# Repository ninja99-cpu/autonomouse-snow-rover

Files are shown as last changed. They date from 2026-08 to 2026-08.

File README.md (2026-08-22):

# Snowbot Rover

An autonomous GPS-guided snowblower rover built on ArduPilot Rover with brushless motors, skid steering, and RC override.

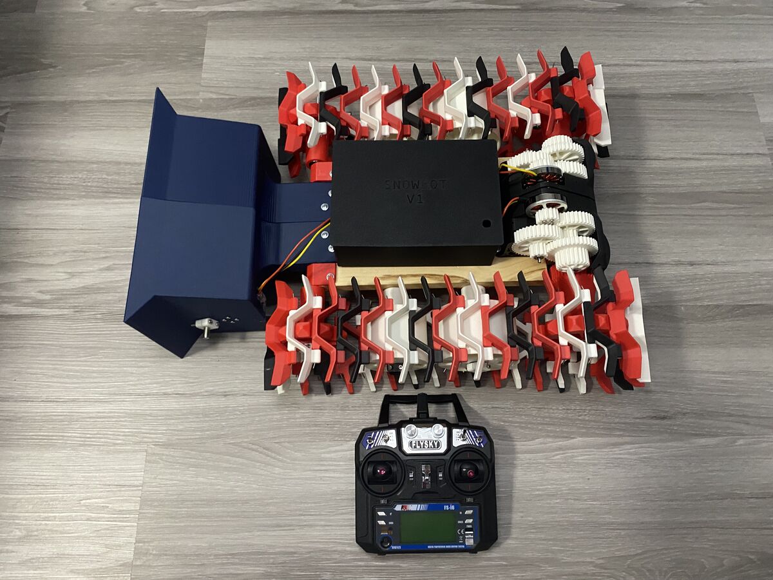
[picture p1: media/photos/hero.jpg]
Snowbot Rover


---

## Overview

Snowbot is a tracked rover designed to autonomously remove snow using a brushless impeller. It runs ArduPilot Rover on an Omnibus F4 flight controller and supports both manual RC control and GPS waypoint navigation. The project was built for an engineering fair and combines embedded systems, power electronics, robotics, and mechanical design.

---

## Features

- Skid steering via two independent brushless drive motors
- Brushless snow impeller controlled independently from the drive system
- Manual RC control via FlySky IBUS
- GPS waypoint navigation via ArduPilot Rover
- Built on the open-source RC Snowcat chassis by RCTestFlight, printed in PLA

---

## Hardware

| Component | Qty | Notes |
|---|---|---|
| 5010 Brushless Motor 360KV 2-6S | 3 | 2x drive, 1x impeller |
| 30A BLHeli ESC (bidirectional, 2-4S) | 2 | Drive motors |
| 40A Waterproof ESC (2-4S) | 1 | Impeller motor |
| Omnibus F4 Flight Controller | 1 | STM32F405 |
| 4S LiPo Battery 6000mAh XT60 | 1 | |
| Power Distribution Board | 1 | 5V regulated output for FC |
| BE-220 GPS Module | 1 | |
| FlySky FS-i6 Transmitter | 1 | |
| FlySky FS-iA6B Receiver | 1 | IBUS protocol |
| 8mm Hardened Steel Linear Bearing Rod 400mm | 4 | |
| F694zz Flanged Ball Bearings (4x11x4mm) | 12 | |
| 22x8x7 Skateboard Bearings | 16 | |
| 4mm Steel Rods (gearbox axles) | 4 | 95mm and 80mm |
| Music Wire 0.055in x 36in | 8 | ~35 x 100mm segments per track |
| Wood Plank | 1 | Chassis base |
| PLA Filament | ~1kg | All project-specific printed parts |

Full BOM in [`hardware/bom.csv`](hardware/bom.csv).

---

## Wiring

### Power
```
Battery (4S LiPo) -> PDB -> ESCs (x3)
                  -> PDB -> Flight Controller (5V)
```

### ESC Outputs

| FC Output | Assignment |
|---|---|
| M1 | Left Drive Motor |
| M2 | Right Drive Motor |
| M3 | Impeller Motor |

Each ESC: Signal (White) and Ground (Black) to FC. Red BEC wire left disconnected — FC is powered from PDB.

### RC Receiver (IBUS)
```
FS-iA6B IBUS Signal -> FC UART RX
FS-iA6B 5V         -> FC 5V
FS-iA6B GND        -> FC GND
```

### GPS
```
GPS TX  -> FC RX
GPS RX  -> FC TX
GPS 5V  -> FC 5V
GPS GND -> FC GND
```

---

## Software

ArduPilot Rover configured for skid steering. Output assignments:

| Parameter | Value |
|---|---|
| SERVO1_FUNCTION | Left Motor |
| SERVO2_FUNCTION | Right Motor |
| SERVO3_FUNCTION | Impeller Motor |

Mission Planner (Windows) was used for all configuration. QGroundControl was tested on macOS but has limited ArduPilot support.

---

## Project Status

| Feature | Status |
|---|---|
| Skid steering | Done |
| RC manual control | Done |
| Brushless motor control | Done |
| Impeller control | Done |
| ArduPilot configuration | Done |
| GPS wiring and configuration | Done |
| Autonomous waypoint navigation | Implemented, field testing pending |
| Compass / magnetometer | Not added |
| Obstacle avoidance | Planned |
| Camera system | Planned |

---

## License

MIT License — see [LICENSE](LICENSE) for details.

---

*Built by Danny Alrayyes*

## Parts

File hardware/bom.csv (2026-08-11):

Component | Quantity | Category | Notes | Source
5010 Brushless Motor 360KV 2-6S | 3 | Motors | 2x drive motors, 1x impeller motor | Amazon
30A BLHeli ESC (bidirectional 2-4S) | 2 | Electronics | Drive motors — reprogrammed for bidirectional | Amazon
40A Waterproof ESC (2-4S) | 1 | Electronics | Impeller motor | Amazon
Omnibus F4 Flight Controller | 1 | Electronics | STM32F405 — running ArduPilot Rover | Amazon
4S LiPo Battery 6000mAh XT60 | 1 | Power |  | Amazon
Power Distribution Board (PDB) | 1 | Power | 5V regulated output for FC | Amazon
BE-220 GPS Module | 1 | Navigation |  | Amazon
FlySky FS-i6 Transmitter | 1 | RC Control |  | Amazon
FlySky FS-iA6B Receiver | 1 | RC Control | IBUS protocol | Amazon
8mm Hardened Steel Linear Bearing Rod 400mm | 4 | Chassis |  | Amazon
F694zz Flanged Ball Bearings (4x11x4mm) | 12 | Bearings |  | Amazon
22x8x7 Skateboard Bearings | 16 | Bearings |  | Amazon
4mm Steel Rod - 95mm (gearbox axle) | 2 | Chassis |  | Amazon
4mm Steel Rod - 80mm (gearbox axle) | 2 | Chassis |  | Amazon
Music Wire 0.055in x 36in | 8 | Tracks | ~35 x 100mm segments per track | Great Hobbies
Wood Plank | 1 | Chassis | See original RC Snowcat design for dimensions | Home Depot
PLA Filament | ~5kg | 3D Printing | All project-specific printed parts | Amazon

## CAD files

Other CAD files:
CAD Files/Gear-cover.f3d
CAD Files/Housing-leftSide.f3d
CAD Files/Housing-rightSide.f3d
CAD Files/Impeller.f3d

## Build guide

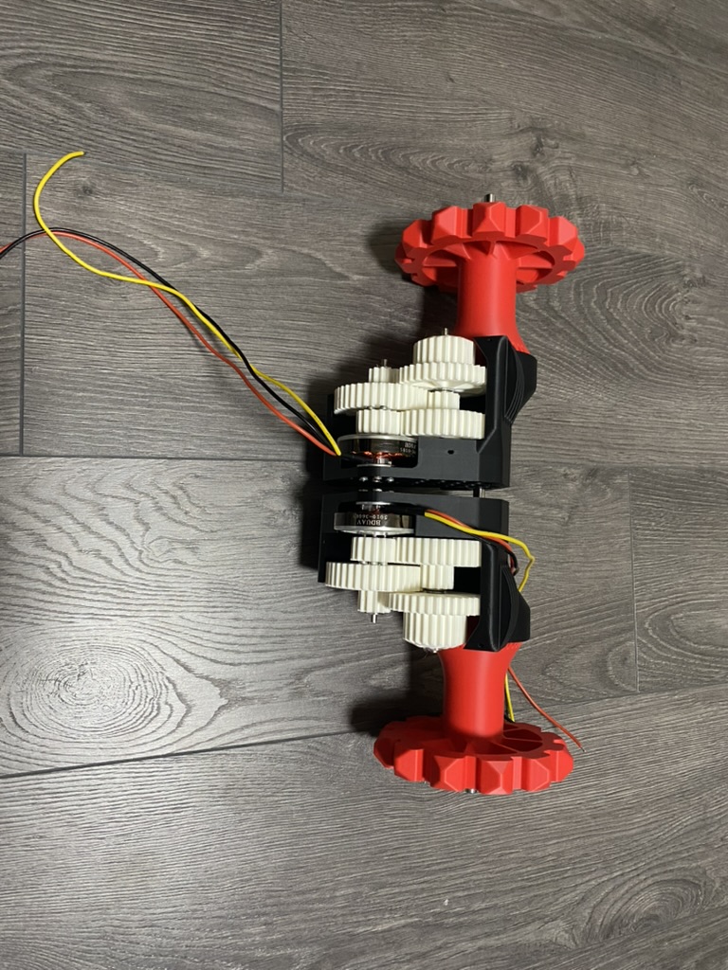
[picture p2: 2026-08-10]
media/photos/build-1.jpg

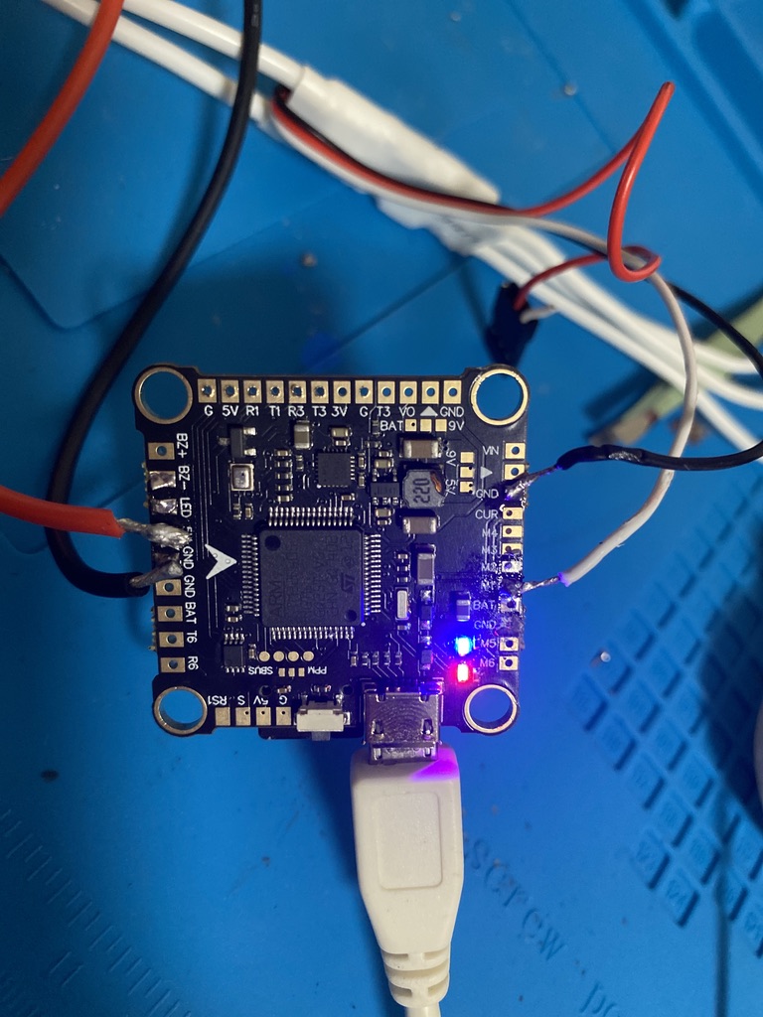
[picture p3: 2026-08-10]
media/photos/build-2.jpg

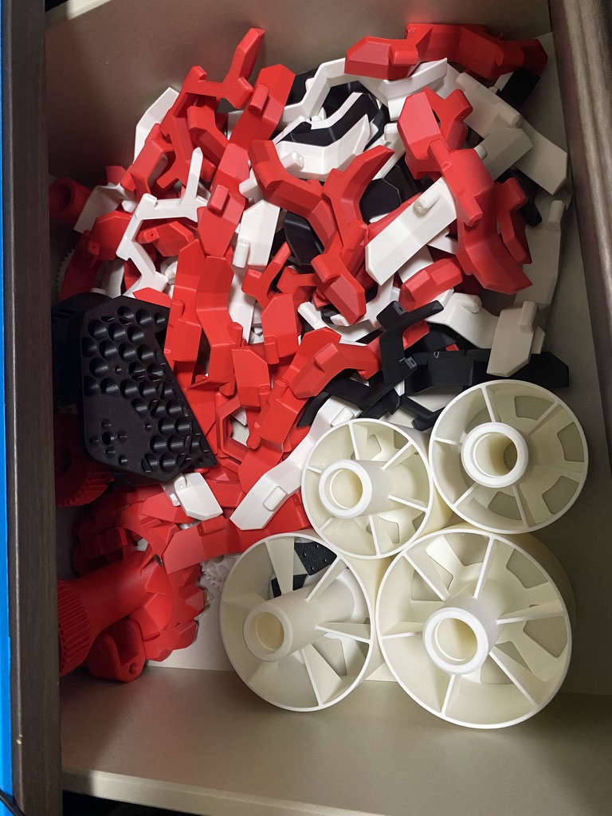
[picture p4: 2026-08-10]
media/photos/build-3.jpg

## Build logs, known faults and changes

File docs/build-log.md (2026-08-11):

# Build Log

## Chassis and Mechanical

- Built on the RC Snowcat open-source design by RCTestFlight
- All structural parts printed in PLA
- Tracks assembled using music wire cut into 100mm segments (~35 per track, 8 lengths of 36" wire total)
- Bearings and axles installed; 8mm hardened steel rods used as main chassis rails
- 5010 360KV motors mounted to drive gearboxes and impeller

## Electronics and Wiring

- Omnibus F4 chosen for ArduPilot Rover compatibility
- PDB installed; regulated 5V line powers the FC
- ESC BEC red wires left disconnected to avoid voltage conflict with PDB
- FlySky receiver wired via IBUS (single signal wire to FC UART)
- BE-220 GPS wired to FC UART

## Firmware and Configuration

- Started with QGroundControl on macOS — ran into limited ArduPilot support and difficulty with motor testing
- Switched to Mission Planner on Windows, which has full ArduPilot support
- Vehicle type set to Rover, drive type set to Skid Steering
- Output functions assigned: SERVO1 = Left Motor, SERVO2 = Right Motor, SERVO3 = Impeller

## Challenges

**ESC beeping on startup**
ESCs beeped continuously on power-up. Power and signal were both present. After investigating output assignments, PWM ranges, and arming settings, the issue came down to incorrect SERVO_FUNCTION parameters and ESC calibration not being completed. Corrected in Mission Planner and resolved after working through calibration.

**Motors not spinning during testing**
Motors would not respond during early motor tests. Investigated arming restrictions, output assignments, and PWM configuration across both QGroundControl and Mission Planner before finding the correct combination of settings that allowed manual motor testing.

**ESC bidirectional mode**
The drive ESCs did not arrive pre-configured for bidirectional operation. It took a while to figure out that BLHeli ESCs need to be reprogrammed for bidirectional mode using BLHeliSuite before they would reverse direction for skid steering.

**GPS and heading**
The BE-220 GPS module was wired and configured but autonomous navigation has not yet been field tested. GPS alone provides position but not heading — a compass or magnetometer would be needed for reliable waypoint navigation. In a future revision a different GPS module would be used, ideally one with a built-in compass.

## Next Steps

- [ ] Field test GPS autonomous navigation
- [ ] Add compass / magnetometer
- [ ] Test impeller in real snow conditions
- [ ] Add camera system for remote monitoring
- [ ] Explore obstacle avoidance (ultrasonic or LiDAR)

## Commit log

2026-08-11 Upload BOM
    [bom.csv]
2026-08-11 Upload custom CAD files
    [Gear-cover.f3d, Housing-leftSide.f3d, Housing-rightSide.f3d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]
